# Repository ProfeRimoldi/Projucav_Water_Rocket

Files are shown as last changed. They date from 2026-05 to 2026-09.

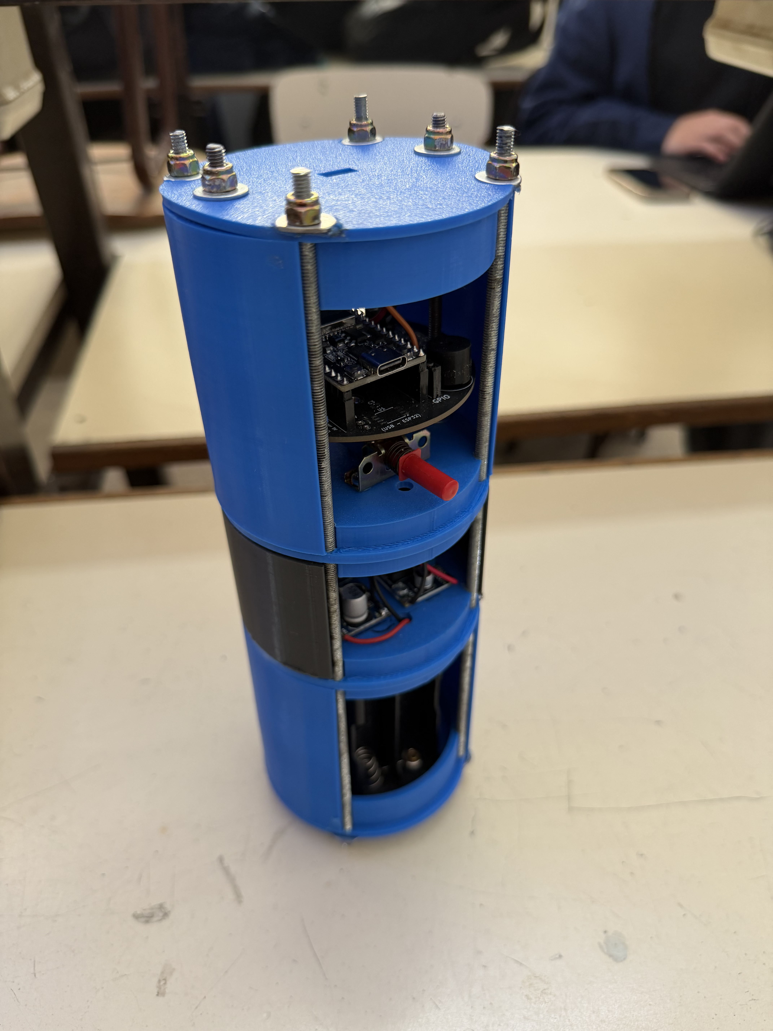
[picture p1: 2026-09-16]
hardware/Photos/IMG_1534.jpeg

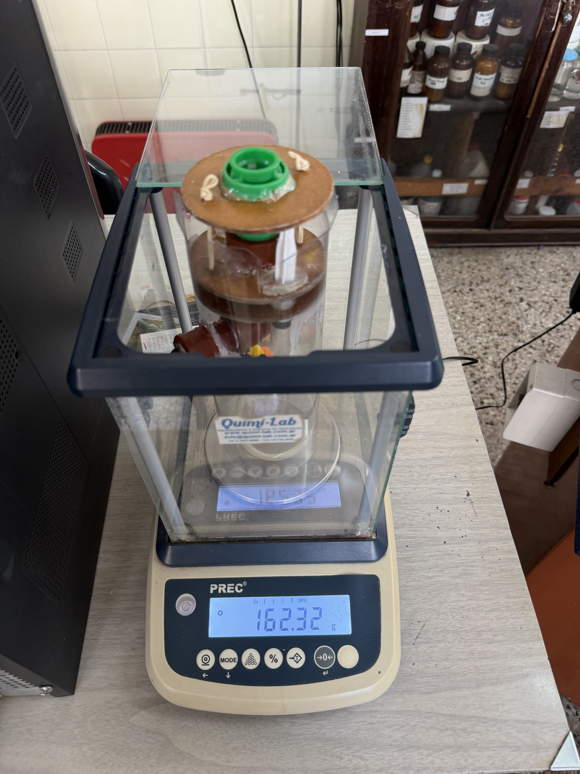
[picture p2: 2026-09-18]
hardware/Photos/IMG_1558.jpeg

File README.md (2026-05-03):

# 🚀 ProJuCAv – Water Rocket with Avionics

## 📡 Descripción del Proyecto

**ProJuCAv (Proyecto de Cohete de Agua con Aviónica)** es una iniciativa educativa basada en metodologías STEM que integra **física, electrónica, programación y diseño mecánico** en el desarrollo de un sistema aeroespacial a escala.

El proyecto propone el diseño, construcción y validación de un **cohete de agua instrumentado**, capaz de medir, registrar y transmitir datos de vuelo en tiempo real.

📘 Inspirado en programas aeroespaciales reales, el enfoque busca trasladar conceptos de ingeniería de alta complejidad a un entorno educativo práctico.

---

## 🎯 Objetivos

* Comprender los principios físicos de la **propulsión por reacción** (Tercera Ley de Newton) 
* Diseñar y construir un vehículo de lanzamiento funcional
* Desarrollar un sistema de **aviónica embarcada**
* Implementar una **estación terrena de telemetría**
* Analizar datos reales de vuelo
* Fomentar el trabajo colaborativo y multidisciplinario

📊 Según la planificación del proyecto, se estructura en etapas progresivas de diseño, integración y validación.

---

## 🧩 Arquitectura del Sistema

El sistema se divide en tres subsistemas principales:

### 🔧 Estructura (Mecánica)

* Botellas PET (fuselaje)
* Aletas aerodinámicas
* Sistema de presurización
* Plataforma de lanzamiento

### ⚡ Aviónica (Electrónica)

* Microcontrolador (ESP32)
* Sensores:

  * Altímetro barométrico (BMP280)
  * Acelerómetro (MPU6050)
* Sistema de almacenamiento local (microSD)
* Módulo de comunicación (LoRa)
* Sistema de alimentación (LiPo + regulación)

📌 La arquitectura electrónica completa se describe en 

---

### 📡 Estación Terrena

* Receptor de telemetría
* Computadora de procesamiento
* Software de visualización en tiempo real

---

## 📡 Telemetría y Adquisición de Datos

El sistema permite:

* Medición de **altura, aceleración y velocidad**
* Registro de datos en tiempo real y post-vuelo
* Transmisión inalámbrica a estación terrena

---

## 🚀 Propulsión

El cohete utiliza propulsión hidráulica basada en:

* Aire comprimido (energía potencial)
* Agua (masa de reacción)

✔ Basado en la **Tercera Ley de Newton**
✔ Expulsión de masa → generación de empuje

---

## 🪂 Sistema de Recuperación

El sistema de recuperación es crítico para la misión:

* Detección de apogeo mediante aviónica.
* Despliegue de paracaídas en apogeo.

---

## 🧪 Etapas del Proyecto

Según la planificación general:

1. **Diseño y fundamentos**
2. **Construcción del cohete**
3. **Integración de aviónica**
4. **Telemetría y pruebas**
5. **Lanzamiento final**

---

## 🛰️ Aviónica – Enfoque del Desarrollo

La aviónica evoluciona en niveles:

* 🔹 Nivel básico: sensores esenciales
* 🔹 Nivel intermedio: registro de datos (caja negra)
* 🔹 Nivel avanzado: telemetría en tiempo real
* 🔹 Nivel completo: sistema autónomo

---

## ⚙️ Tecnologías Utilizadas

* ESP32 (control principal)
* Sensores MEMS
* Comunicación inalámbrica

---

## 📁 Estructura del Repositorio

```bash
Projucav_Water_Rocket/
│
├── firmware/        # Código del sistema embebido
├── hardware/        # Diseño electrónico y PCB
├── docs/            # Documentación técnica y académica
└── README.md        # Descripción general del proyecto
```

---

## 👨‍🏫 Contexto Educativo

* Institución: Instituto Juan XXIII
* Modalidad: Aprendizaje basado en proyectos (PBL)
* Duración: ~5 meses
* Trabajo en equipos multidisciplinarios

---

## 🎓 Enfoque del Proyecto

Este proyecto busca replicar, a escala educativa, un sistema aeroespacial real, integrando:

* Ingeniería electrónica
* Física aplicada
* Programación embebida
* Diseño mecánico
* Análisis de datos

---

## 🚀 Autores / Desarrollo

**Diego Otero**; **Damián Rimoldi**
* Ingeniería en Electrónica – Docentes – Investigadores

Quien escribe:
Responsable del desarrollo de la **aviónica y sistema electrónico** del proyecto.

---

## 📌 Estado del Proyecto

🟡 En desarrollo
🔧 Etapa: Diseño e integración de sistemas

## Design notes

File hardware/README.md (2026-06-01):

Hardware Documentation.

Conexión de sensores: Usar firmware para detectar direcciones (ya cargado)
-MPU6050 (gyro) en bus I2C: DIR: 0x68
-BMP280 (Atmosferic Pressure) en bus I2C: Dir: 0x77

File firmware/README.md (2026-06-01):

# Aviónica y Telemetría en Tiempo Real - Projucav Water Rocket

Este módulo del repositorio contiene el firmware de la aviónica embarcada y de la estación terrena para el desarrollo del cohete de agua. El sistema adquiere dinámicamente datos de aceleración triaxial y altitud barométrica, implementa algoritmos de calibración y filtrado por cambio significativo en el emisor, y transmite la telemetría vía radioenlace LoRa hacia la estación terrena.

---

## 🚀 Arquitectura del Sistema

El proyecto está compuesto por dos nodos basados en microcontroladores ESP32:

1. **Nodo Emisor (Emisor_V1.ino):** Firmware embarcado en el PCB del cohete. Se encarga de la inicialización de los sensores I2C, el cálculo de offsets, el filtrado inercial/barométrico y el empaquetado de datos en formato CSV para su transmisión.
2. **Nodo Receptor (Receptor_V1.ino):** Firmware de la Estación Terrena. Escucha el espectro de RF, decodifica las ráfagas entrantes en tiempo real, procesa una máquina de estados para el análisis dinámico del vuelo y la detección automática del Apogeo.

---

## 🛠️ Especificaciones de Hardware y Conectividad

### Asignación de Pines (Pinout)

Ambos PCBs dedicados implementan transceptores LoRa basados en la tecnología Semtech (SX1276/SX1278) interconectados mediante el bus SPI nativo (VSPI) de la ESP32:

| Señal LoRa | Pin ESP32 (Emisor) | Pin ESP32 (Receptor) |
| :--- | :---: | :---: |
| **MOSI** | GPIO 23 | GPIO 23 |
| **MISO** | GPIO 19 | GPIO 19 |
| **SCK** | GPIO 18 | GPIO 18 |
| **SS (CS)** | GPIO 5 | GPIO 5 |
| **DI0 (IRQ)**| GPIO 17 | GPIO 17 |
| **RST** | GPIO 2 | *No utilizado (-1)* |

### Direccionamiento I2C (Sensores Embarcados)
* **Acelerómetro / Giroscopio (MPU6050):** `0x68`
* **Sensor de Presión / Altímetro (BMP280):** `0x76` *(Dirección física corregida)*

> ⚠️ **Nota de Orientación del PCB:** El MPU6050 se encuentra montado de forma **vertical** en el PCB del cohete. Por consiguiente, el **Eje X** ha sido mapeado por software como el eje de Empuje Vertical Primario.

---

## ⚙️ Características Principales del Firmware

### 1. Calibración Automática en Rampa
Al inicializar el Emisor, el programa ejecuta una rutina de promediado estático (20 muestras) para aislar las desviaciones térmicas y mecánicas (*offsets*) de ambos sensores:
* Establece una **Línea de Base Barométrica** dinámica para fijar la altitud inicial en `0.00 metros` relativos al suelo de lanzamiento.
* Resta la aceleración inercial en reposo en los ejes laterales y compensa el eje X respecto a la gravedad local ($9.81 m/s^2$) para obtener la lectura de **Empuje Neto**.

### 2. Filtrado por Cambio Significativo (*Deadband*)
Con el fin de mitigar el ruido de fase en la rampa, economizar batería y optimizar el uso del espectro de RF de LoRa, el emisor implementa reportes por umbral dinámico:
* **Umbral de Empuje:** $\ge 0.60 m/s^2$
* **Umbral de Altitud:** $\ge 0.50 metros$
* **Transmisión de Respaldo (*Heartbeat*):** Si las variables no superan los umbrales (cohete estático), se fuerza un envío cíclico de seguridad cada `2000 ms` para validar la continuidad del enlace.

### 3. Analizador de Estados de Vuelo y Detección de Apogeo
El firmware de la estación terrena decodifica la cadena CSV recibida y evalúa los vectores de telemetría a través de una máquina de estados:
* **`EN RAMPA`**: Estado inicial de espera.
* **`PROPULSIÓN / ASCENSO`**: Se gatilla automáticamente al detectar un $Empuje > 15.0 m/s^2$.
* **`¡APOGEO DETECTADO!`**: Se procesa mediante la derivada temporal de la altitud. Al registrar `3 lecturas consecutivas descendentes` tras haber alcanzado la altura máxima, la estación confirma el apogeo y emite una alerta crítica visual. El algoritmo está diseñado para actuar como el disparador lógico del sistema de eyección del paracaídas.
* **`DESCENSO`**: Monitoreo de velocidad terminal hasta el aterrizaje.

---

## 💾 Dependencias Requeridas

Para compilar y flashear estos programas desde el IDE de Arduino, es necesario instalar las siguientes librerías desde el Gestor de Bibliotecas:

* **LoRa** (por *Sandeep Mistry*)
* **Adafruit MPU6050** (por *Adafruit*)
* **Adafruit BMP280 Library** (por *Adafruit*)
* **Adafruit Unified Sensor** (por *Adafruit*)

---

## 📊 Formato del Paquete de Datos (Telemetría Raw)

Las ráfagas transmitidas por el módulo de radio viajan de forma compacta en una única cadena de texto plana separada por comas (CSV), reduciendo el tiempo de aire al mínimo:

```csv
[Empuje_Neto_X],[Aceleracion_Y],[Aceleracion_Z],[Altitud_Relativa]

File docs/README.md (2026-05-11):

General Projetc Documentation and To-Do List:

-Agregar conexión a servo en OBC, en pin GPIO25 (pin 9 en OBC, RXGPS) el pin de PWM de éste. Conectar 5V de una fuente aparte para el consumo.

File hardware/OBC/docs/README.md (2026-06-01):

# Documentation - OBC

Esta carpeta contiene documentación técnica complementaria del proyecto.

## Contenido esperado

- decisiones de diseño
- notas de ingeniería
- cambios importantes entre revisiones
- cálculos relevantes
- validaciones y pruebas
- observaciones de fabricación
- incidencias detectadas en laboratorio

## Objetivo

Mantener trazabilidad técnica del desarrollo del hardware y facilitar futuras revisiones o rediseños.

## Decisiones de Diseño:

- En OBC se necesita agregar el sensor de presión atmosférica BMP280, para ello, tanto el giróscopo MPU6050 como el sensor de presión atmosférica compartirán el bus I2C, y se detectan las direcciónes físicas de los sensores mediante el firmware I2C_scanner.ino presente en el apartado "firmware" de la documentación.
- Se conectaron en paralelo ambos sensores usando el mismo bus I2C.

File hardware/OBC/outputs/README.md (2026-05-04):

# Outputs - OBC

Esta carpeta contiene los archivos de fabricación y exportación del PCB de la OBC Dev Board.

## Estructura

### Rev_A

Primera revisión formal de fabricación de la placa.

Contenido esperado:

- Gerbers
- Drill files
- PDF del esquemático
- Imágenes del PCB
- BOM (Bill of Materials)

## Notas

Solo deben guardarse aquí versiones consolidadas listas para fabricación o revisión formal.

No utilizar esta carpeta para archivos temporales, backups automáticos o pruebas intermedias.

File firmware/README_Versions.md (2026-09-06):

# Aviónica de Cohete de Agua — ESP32 + LoRa

File Name: EMISOR_apogeo_V2_Test
Firmware para la placa de aviónica embarcada en un cohete de agua. Lee acelerómetro y presión barométrica, detecta el despegue y el apogeo mediante una máquina de estados, y transmite telemetría por LoRa a una estación en tierra.

## Hardware

| Componente | Modelo | Notas |
|---|---|---|
| Microcontrolador | ESP32 (devkit genérica) | |
| Radio | Módulo LoRa (SX127x) a 433 MHz | |
| IMU | MPU6050 | I2C, dirección `0x68` |
| Barómetro | BMP280 | I2C, dirección `0x76` |
| Buzzer | Piezoeléctrico **pasivo** | Requiere `tone()`, no sirve con `digitalWrite` |
| Servo | Genérico (ej. liberación de paracaídas) | Alimentar aparte del 3.3V si mueve algo con resistencia |
| LED | Integrado de la placa | Verificar el pin real en tu devkit específica |

### Conexión de pines

| Señal | GPIO |
|---|---|
| LoRa SS | 5 |
| LoRa RST | 2 |
| LoRa DIO0 | 17 |
| I2C (MPU6050 + BMP280) | 21 (SDA) / 22 (SCL), por defecto |
| Buzzer | 15 |
| Servo | 13 |
| LED | 2 (fallback si la placa no define `LED_BUILTIN`) |

> ⚠️ En algunas devkits el LED integrado está en el mismo GPIO2 que el `RST` del LoRa. Confirmá el pin real de tu placa antes de volar.

## Dependencias (Arduino Library Manager)

- `LoRa` (sandeepmistry)
- `Adafruit MPU6050`
- `Adafruit BMP280`
- `Adafruit Unified Sensor`
- `ESP32Servo` (Kevin Harrington)

## Máquina de estados

```
EN_RAMPA → ASCENSO → DESCENSO → FINALIZADO
```

- **EN_RAMPA → ASCENSO**: empuje neto sostenido por encima de `UMBRAL_DESPEGUE` durante `MUESTRAS_DESPEGUE` lecturas consecutivas.
- **ASCENSO → DESCENSO (apogeo)**: la altitud cae `HISTERESIS_APOGEO` metros por debajo del máximo alcanzado, sostenido por `MUESTRAS_APOGEO` lecturas (evita falsos positivos por ruido).
- **DESCENSO → FINALIZADO**: altitud por debajo de `UMBRAL_ATERRIZAJE` sostenida por `MUESTRAS_ATERRIZAJE` lecturas.

Las lecturas de altitud y empuje se suavizan con un filtro de media móvil exponencial (`ALPHA_ALTITUD`, `ALPHA_EMPUJE`) antes de evaluarse en la máquina de estados.

## Al detectar el apogeo

1. Se enciende el LED y suena el buzzer (no bloqueante).
2. El servo se mueve a `ANGULO_APOGEO`.
3. Se envía por LoRa un paquete inmediato `APOGEO,<altura>`.
4. Se espera hasta `ACK_TIMEOUT_MS` una respuesta `ACK_APOGEO,<rssi>,<snr>` de la estación en tierra.
5. Se imprime por Serial y se retransmite por LoRa un cartel con la altura y, si llegó a tiempo, el RSSI/SNR medidos en tierra.

> El RSSI/SNR de un paquete solo los conoce quien lo recibe. Para que estos valores no aparezcan siempre como "sin confirmación", la estación en tierra debe responder con `ACK_APOGEO,<rssi>,<snr>` al recibir un paquete `APOGEO,...` (usando `LoRa.packetRssi()` / `LoRa.packetSnr()`).

## Telemetría regular

Además del aviso de apogeo, se envía telemetría periódica por LoRa (formato CSV: empuje, acc_y, acc_z, altitud, estado) cada vez que hay un cambio significativo en empuje o altitud, o cada `TIMEOUT_FORZADO` ms como respaldo.

## Modo simulación

Para probar toda la lógica de la máquina de estados en el escritorio, sin sensores, cohete ni radio conectados:

```cpp
#define MODO_SIMULACION true
```

Esto genera un perfil de vuelo sintético (reposo → impulso → coast → apogeo → caída → aterrizaje) con ruido incluido, útil para validar umbrales antes de una prueba real. Volver a `false` para vuelo real.

## Calibración

Al arrancar (fuera de modo simulación), el firmware promedia 20 muestras de presión y aceleración con la placa quieta para fijar la presión de referencia (altitud 0) y los offsets del acelerómetro. **No mover la placa durante este proceso.**

File Name: EMISOR_apogeo_V3_Test
# Aviónica de Cohete de Agua — ESP32 + LoRa (sin LED / sin RSSI-SNR)

Firmware para la placa de aviónica embarcada en un cohete de agua. Lee acelerómetro y presión barométrica, detecta el despegue y el apogeo mediante una máquina de estados, y transmite telemetría por LoRa a una estación en tierra.

Esta es la versión simplificada: sin indicador LED y sin protocolo de confirmación de RSSI/SNR con la estación en tierra (por lo tanto, sin pausas ni esperas bloqueantes en ningún punto del `loop`).

## Hardware

| Componente | Modelo | Notas |
|---|---|---|
| Microcontrolador | ESP32 (devkit genérica) | |
| Radio | Módulo LoRa (SX127x) a 433 MHz | |
| IMU | MPU6050 | I2C, dirección `0x68` |
| Barómetro | BMP280 | I2C, dirección `0x76` |
| Buzzer | Piezoeléctrico **pasivo** | Requiere `tone()`, no sirve con `digitalWrite` |
| Servo | Genérico (ej. liberación de paracaídas) | Alimentar aparte del 3.3V si mueve algo con resistencia |

### Conexión de pines

| Señal | GPIO |
|---|---|
| LoRa SS | 5 |
| LoRa RST | 2 |
| LoRa DIO0 | 17 |
| I2C (MPU6050 + BMP280) | 21 (SDA) / 22 (SCL), por defecto |
| Buzzer | 15 |
| Servo | 13 |

## Dependencias (Arduino Library Manager)

- `LoRa` (sandeepmistry)
- `Adafruit MPU6050`
- `Adafruit BMP280`
- `Adafruit Unified Sensor`
- `ESP32Servo` (Kevin Harrington)

## Máquina de estados

```
EN_RAMPA → ASCENSO → DESCENSO → FINALIZADO
```

- **EN_RAMPA → ASCENSO**: empuje neto sostenido por encima de `UMBRAL_DESPEGUE` durante `MUESTRAS_DESPEGUE` lecturas consecutivas.
- **ASCENSO → DESCENSO (apogeo)**: la altitud cae `HISTERESIS_APOGEO` metros por debajo del máximo alcanzado, sostenido por `MUESTRAS_APOGEO` lecturas (evita falsos positivos por ruido).
- **DESCENSO → FINALIZADO**: altitud por debajo de `UMBRAL_ATERRIZAJE` sostenida por `MUESTRAS_ATERRIZAJE` lecturas.

Las lecturas de altitud y empuje se suavizan con un filtro de media móvil exponencial (`ALPHA_ALTITUD`, `ALPHA_EMPUJE`) antes de evaluarse en la máquina de estados.

## Al detectar el apogeo

1. Suena el buzzer (no bloqueante).
2. El servo se mueve a `ANGULO_APOGEO`.
3. Se imprime por Serial y se retransmite por LoRa un cartel con la altura del apogeo:

```
**********************************************
           !!! APOGEO DETECTADO !!!
**********************************************
Altura del apogeo: 153.72 m
**********************************************
```

No hay espera de confirmación de la estación en tierra: el `loop` sigue de largo sin pausas.

## Telemetría regular

Además del aviso de apogeo, se envía telemetría periódica por LoRa (formato CSV: empuje, acc_y, acc_z, altitud, estado) cada vez que hay un cambio significativo en empuje o altitud, o cada `TIMEOUT_FORZADO` ms como respaldo.

## Modo simulación

Para probar toda la lógica de la máquina de estados en el escritorio, sin sensores, cohete ni radio conectados:

```cpp
#define MODO_SIMULACION true
```

Esto genera un perfil de vuelo sintético (reposo → impulso → coast → apogeo → caída → aterrizaje) con ruido incluido, útil para validar umbrales antes de una prueba real. Volver a `false` para vuelo real.

## Calibración

Al arrancar (fuera de modo simulación), el firmware promedia 20 muestras de presión y aceleración con la placa quieta para fijar la presión de referencia (altitud 0) y los offsets del acelerómetro. **No mover la placa durante este proceso.**

File Name: EMISOR_apogeo_V3_Test
Se bajó el filtro del sensor BMP6050

File Name: EMISOR_apogeo_V6_lora_opcional
Si no detecta el modulo LoRa inicia igual.

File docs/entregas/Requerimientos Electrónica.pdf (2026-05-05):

## Resumen de requerimientos de electrónica – ProJuCAv

La parte electrónica del proyecto debe resolver, como mínimo, cinco funciones principales:

## 1. Unidad de control

Debe existir un microcontrolador central que actúe como cerebro del sistema y procese sensores, tome decisiones y controle salidas.En los materiales se propone como opción recomendada el ESP32, por su mayor capacidad de procesamiento, conectividad y posibilidad de trabajar con telemetría, microSD y control de actuadores.

### Requerimiento:

- seleccionar e integrar una placa basada en ESP32
- definir entradas, salidas y buses de comunicación
- ejecutar la lógica general del vuelo

## 2. Sensado de variables de vuelo

El sistema electrónico debe poder medir variables físicas del vuelo para reconstruir lo ocurrido y tomar decisiones automáticas.
Los documentos plantean como sensores principales:
- BMP280/BME280 para presión y cálculo de altura
- MPU6050 para aceleración y dinámica del vuelo

### Requerimiento:

- medir presión/altura
- medir aceleración
- tomar muestras con frecuencia suficiente para registrar el vuelo
- filtrar y procesar esas mediciones para detectar eventos

## 3. Detección de eventos de misión

La electrónica no solo debe medir: también debe interpretar el vuelo. De acuerdo con los materiales, los eventos principales son:
- detección de lanzamiento
- seguimiento del ascenso
- detección de apogeo
- gestión del descenso
Además, en el material de recuperación se remarca que el punto crítico es desplegar en el apogeo, no por tiempo fijo.

### Requerimiento:

- desarrollar firmware con máquina de estados
- detectar lanzamiento a partir del IMU
- detectar apogeo principalmente con barómetro
- validar eventos con lógica robusta para evitar falsos disparos

## 4. Actuación del sistema de recuperación

La electrónica debe poder accionar el mecanismo de recuperación.
Los PDFs muestran como opción didáctica y segura el uso de un servo mecánico para liberar el paracaídas o una tapa/escotilla.

### Requerimiento:

- controlar un servo
- mantenerlo inhibido hasta que el firmware autorice el disparo
- ejecutar la liberación en el apogeo
- asegurar una secuencia de despliegue confiable

## 5. Registro de datos

El proyecto contempla el concepto de “caja negra”, almacenando variables del vuelo en una microSD para análisis posterior.

### Requerimiento:

- guardar datos del vuelo en microSD
- registrar al menos:
- tiempo
- altura
- aceleración
- estado del sistema
- tensión de batería
- evento de despliegue

## 6. Telemetría / enlace con estación terrena

La arquitectura general del proyecto incluye un enlace entre el vehículo y la estación terrena para recibir datos en tiempo real. Esto aparece tanto en la planificación general como en los documentos de diseño electrónico.

### Requerimiento:

- transmitir datos hacia una estación terrena
- definir si el enlace será por:
- WiFi del ESP32
- RF 433 MHz
- otro medio equivalente (LoRa)
- permitir visualización y registro en tierra

## 7. Alimentación del sistema

La electrónica necesita una alimentación embarcada estable. En el material se propone una LiPo de 3,7 V con regulación para obtener tensiones estables, remarcando que la estabilidad eléctrica es crítica frente a vibraciones y caídas de tensión.

### Requerimiento:

- usar una batería embarcada
- regular tensión para alimentar:
- ESP32
- sensores
- servo
- contemplar desacople y robustez eléctrica
- monitorear nivel de batería

## 8. Interfaz de estado y diagnóstico

En la evolución del proyecto aparece la necesidad de contar con indicadores de estado, por ejemplo LED, datos de batería y señales de sistema listo.

### Requerimiento:

- incorporar al menos un LED de estado
- opcionalmente buzzer o interfaz serial
- indicar:
- encendido
- sistema listo
- armado
- vuelo
- error

## 9. Integración física dentro del cohete

La planificación del proyecto muestra que la aviónica debe integrarse físicamente dentro del vehículo, y que una de las metas de la fase de aviónica es justamente el montaje del sistema electrónico dentro de la estructura y los ajustes de balance de masa.

### Requerimiento:

- definir volumen y ubicación de la aviónica
- asegurar fijación mecánica
- ordenar cableado
- coordinar con la estructura y con el sistema de recuperación
- respetar restricciones de masa y espacio

## 10. Ensayos y validación

La planificación general contempla una etapa específica de verificación de enlace, ensayos en frío y validación del sistema completo antes del lanzamiento final.

### Requerimiento:

- realizar pruebas de:
- lectura de sensores
- registro en SD
- telemetría
- servo
- alimentación
- validar la lógica de disparo antes del vuelo
- participar en la secuencia de ensayo general tipo go/no-go

## Lista práctica de entregables electrónicos

- arquitectura electrónica definida
- selección de componentes
- esquema de conexiones
- firmware con máquina de estados
- lectura de BMP280/BME280
- lectura de MPU6050
- control de servo
- guardado en microSD
- telemetría básica
- alimentación estable con batería
- indicadores de estado
- protocolo de pruebas

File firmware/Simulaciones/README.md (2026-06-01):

# 📊 Módulo de Simulación de Vuelo (Inyector de Datos)

Este directorio contiene las herramientas de simulación de software diseñadas para validar y ensayar la lógica de la estación terrena (`Receptor_V1.ino`) en banco de pruebas, sin necesidad de realizar lanzamientos físicos ni exponer los sensores a desgastes mecánicos.

---

## 📐 Modelo Matemático Continúo (Parábola 0 a 0)

Para lograr una visualización óptima en el **Serial Plotter** del IDE de Arduino (el cual posee un búfer horizontal limitado a 500 muestras), el firmware del emisor simulado implementa una función cuadrática continua en el tiempo. Esto permite modelar de forma simétrica el ascenso y descenso del cohete de agua, asegurando que la trayectoria inicie exactamente en `0.00 metros` y finalice en `0.00 metros`.

La ecuación analítica implementada para la altitud $h(t)$ en función del tiempo $t$ es:

$$h(t) = a \cdot t \cdot (t_{total} - t)$$

Donde:
* $t_{total} = 6.0 \text{ segundos}$ (Tiempo total estimado de vuelo).
* $h_{max} = 35.0 \text{ metros}$ (Apogeo teórico parametrizado en el vértice $t = 3.0\text{s}$).
* $a = \frac{4 \cdot h_{max}}{t_{total}^2}$ (Constante de curvatura para ajustar el apogeo).

---

## ⏱️ Optimización del Espectro y Tasa de Muestreo

A diferencia del firmware de vuelo real (`Emisor_V1.ino`) que adquiere datos a 50 Hz, el emisor de simulación opera con un diferencial de tiempo comprimido:
* **Paso de tiempo ($\Delta t$):** $0.4 \text{ segundos}$.
* **Retardo del lazo (`delay`):** $400 \text{ milisegundos}$.

Esta tasa de refresco reducida permite que todo el perfil de vuelo de 6 segundos se resuelva en **16 puntos de datos** de telemetría. Gracias a esto, la curva parabólica completa se dibuja de forma estática en la pantalla del Serial Plotter del receptor, evitando que el gráfico se desplace hacia la izquierda (*scrolling*) y permitiendo un análisis visual completo del despegue y aterrizaje.

---

## 📑 Perfil de Telemetría Generado (Vectores de Fuerza)

El simulador discrimina los estados físicos del cohete de la siguiente manera:

1. **Fase de Propulsión ($0.0\text{s} \le t \le 0.4\text{s}$):** Simula la expulsión violenta de agua a presión. Presenta un pico de empuje positivo inicial de $45.0 \text{ m/s}²$ que decrece rápidamente.
2. **Fase Inercial y Caída Libre ($t > 0.4\text{s}$):** El empuje cesa. El acelerómetro pasa a registrar instantáneamente la aceleración de la gravedad pura ($-9.81 \text{ m/s}²$), mientras la altitud barométrica continúa su ascenso inercial hacia el vértice y su posterior descenso.
3. **Fase de Impacto ($t \ge 6.0\text{s}$):** Al tocar tierra de forma controlada, tanto la altitud como el empuje neto se fuerzan analíticamente a `0.00` para estabilizar las líneas del gráfico.

---

## 💻 Procedimiento de Ensayo en Banco

1. Flashear la placa de la Estación Terrena con el código receptor analítico.
2. Flashear la placa del Cohete con el código del **Emisor Simulado** ubicado en esta carpeta.
3. Conectar ambas placas por USB, abrir el **Serial Plotter** en el puerto del receptor (configurado a **115200 baudios**).
4. Abrir el Monitor Serie común en el puerto del emisor, escribir la letra `D` (Despegue) y presionar *Enter*.
5. **Resultado esperado:** El receptor graficará en tiempo real la parábola de altitud en sincronía con los cambios de estado de la aviónica, permitiendo verificar la sensibilidad del algoritmo de detección de apogeo.

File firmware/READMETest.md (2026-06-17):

# 🚀 Sistema de Aviónica y Telemetría - Cohete de Agua

Este repositorio contiene las iteraciones de firmware desarrolladas para la computadora de a bordo y la estación terrena del proyecto del cohete de agua. El ecosistema de software está diseñado para abarcar desde las pruebas iniciales de hardware en laboratorio hasta el análisis dinámico de telemetría inalámbrica en tiempo real durante el vuelo.

---

## 🛠️ Estructura del Firmware y Características Técnicas

El ecosistema de código se divide en cuatro módulos principales con objetivos específicos:

### 1. `Medicion_1.ino` (Fase de Diagnóstico y Banco de Pruebas)
* [cite_start]**Propósito:** Actúa como un script básico de validación y diagnóstico inicial para comprobar la conectividad física de los periféricos en el bus $I^2C$[cite: 139].
* [cite_start]**Direccionamiento de Hardware:** Inicializa de forma directa el acelerómetro/giroscopio MPU6050 en la dirección fija `0x68` y el barómetro BMP280 en la dirección `0x76`[cite: 139, 150, 151].
* **Tratamiento Físico:** Carece de rutinas de calibración activa. [cite_start]Calcula la altitud utilizando una presión de referencia fija estandarizada al nivel del mar de $1013.25 \text{ hPa}$[cite: 140]. No descuenta el vector de la gravedad terrestre de los ejes analizados.
* [cite_start]**Tasa de Adquisición:** Configura un retraso estricto de `100 ms` ($10 \text{ Hz}$) en el bucle de ejecución[cite: 174], ideal únicamente para la inspección visual inicial en el monitor serie.

### 2. `Medicion_2.ino` (Computadora de A Bordo - Monitoreo Local)
* **Propósito:** Firmware de telemetría local enfocado en la estabilidad de datos, mitigación de ruido mecánico y análisis analítico en rampa.
* **Calibración del Origen ($0\text{ m}$):** Durante el primer segundo del arranque (`setup`), toma un promedio de 20 muestras de la presión atmosférica del entorno para fijar la presión base real ($P_{\text{base}}$), garantizando que la altitud relativa inicie exactamente en $0 \text{ metros}$ sin importar las condiciones climáticas.
* **Cálculo de Empuje Neto:** Integra una rutina para calcular los offsets de los sensores en reposo. Al eje vertical (eje X) se le sustrae el vector de la aceleración de la gravedad terrestre ($g = 9.81 \text{ m/s}^2$) para aislar el error neto del chip y medir el empuje puro del motor.
* **Filtrado Analógico/Digital:** * **MPU6050:** Activa el filtro digital pasabajo (DLPF) a una banda de `21 Hz` para amortiguar las vibraciones estructurales de alta frecuencia del cohete.
  * **BMP280:** Configura un filtro IIR $\times16$ junto a un sobremuestreo de presión de $\times16$ para suavizar picos espurios provocados por corrientes dinámicas de viento durante el ascenso.

### 3. `Emisor_V1.ino` (Computadora de A Bordo - Firmware de Vuelo Principal)
* **Propósito:** Es el código definitivo integrado en el hardware del cohete. [cite_start]Fusiona las funciones analíticas de calibración con la ráfaga de transmisión inalámbrica LoRa[cite: 139].
* [cite_start]**Lógica de Filtrado por Cambio Significativo (Smart Telemetry):** Para no saturar el canal inalámbrico (debido a la baja tasa de transferencia del enlace LoRa de largo alcance), el bucle interroga internamente a los sensores a una velocidad de $50 \text{ Hz}$ (`20 ms`) [cite: 173, 174] para capturar el instante exacto del despegue, pero solo transmite vía radio si se cumplen los siguientes criterios:
  * [cite_start]$\Delta_{\text{Empuje}} \ge 0.60 \text{ m/s}^2$ (Variación brusca de aceleración en el eje vertical X)[cite: 141, 142].
  * [cite_start]$\Delta_{\text{Altitud}} \ge 0.50 \text{ m}$ (Desplazamientos verticales superiores a 50 cm)[cite: 142, 143].
  * [cite_start]**Heartbeat de Seguridad:** Transmisión forzada por timeout si transcurren `2000 ms` sin cambios significativos [cite: 144, 145][cite_start], permitiendo validar el estado de la aviónica en tierra antes del lanzamiento[cite: 145].
* [cite_start]**Configuración RF LoRa:** Opera a una frecuencia de `433 MHz` [cite: 147][cite_start], con un ancho de banda de `125 kHz` [cite: 147, 148][cite_start], Spreading Factor `SF7` para optimizar velocidad [cite: 148] [cite_start]y una potencia máxima de transmisión configurada en `17 dBm`[cite: 148, 149].

### 4. `Receptor_V1.ino` (Estación Terrena - Módulo Receptor)
* **Propósito:** Firmware exclusivo de la placa receptora de telemetría que permanece en la base de lanzamiento conectada a la computadora terrena.
* **Operación Inalámbrica:** Configura el módulo LoRa en modo escucha asíncrona a `433 MHz` utilizando interrupciones de hardware en el pin digital `DI0` de la placa.
* [cite_start]**Parseo Analítico de Datos:** Recibe la cadena compacta en formato CSV generada por el emisor[cite: 131], procesa la posición de los delimitadores por comas y extrae ordenadamente los valores de Empuje Neto (X), Aceleraciones Laterales (Y, Z) y Altitud Relativa para mostrarlos de forma legible en el terminal serie de la PC.
* **Modo Tolerancia a Fallos:** Si la trama de datos sufre degradación de señal o interferencias mecánicas en el aire, el código omite el parseo y despliega la cadena de texto cruda en bruto (`Raw`) para evitar bloqueos del software.

---

## 📊 Matriz de Comparación Operativa

| Especificación Técnica | `Medicion_1.ino` | `Medicion_2.ino` | `Emisor_V1.ino` | `Receptor_V1.ino` |
| :--- | :---: | :---: | :---: | :---: |
| **Ubicación Física** | Cohete (Banco) | Cohete (Local) | Cohete (Vuelo) | Estación Terrena |
| **Buses de Interfaz** | $I^2C$ | $I^2C$ | $I^2C$ + SPI (LoRa) | SPI (Módulo LoRa) |
| **Frecuencia del Bucle** | $10 \text{ Hz}$ (`100ms`) | $10 \text{ Hz}$ (`100ms`) | $50 \text{ Hz}$ (`20ms` interno) | Asíncrono (RX Polling) |
| **Calibración Dinámica** | No | Sí (Fija Origen $0\text{m}$) | Sí (Fija Origen $0\text{m}$) | No aplica |
| **Filtrado Activo (DLPF)** | No | Sí (Banda a `21 Hz`) | Sí (Banda a `21 Hz`) | No aplica |
| **Criterio de Disparo** | Transmisión Continua | Transmisión Continua | Umbrales dinámicos / Heartbeat | Recepción de paquete válido |
| **Formato de Salida** | Texto Serie | Texto Serie | String CSV Compacto | Formateado / Raw en consola |

---

## 📡 Protocolo y Estructura de la Trama CSV

[cite_start]La comunicación inalámbrica entre la aviónica del cohete (`Emisor_V1.ino`) y la estación terrena (`Receptor_V1.ino`) utiliza un formato de cadena comprimido delimitado por comas[cite: 131]:

```text
Formato: <Empuje_Neto_X>,<Acc_Lateral_Y>,<Acc_Lateral_Z>,<Altitud_Relativa>
Ejemplo: 12.34,-0.45,0.12,38.50

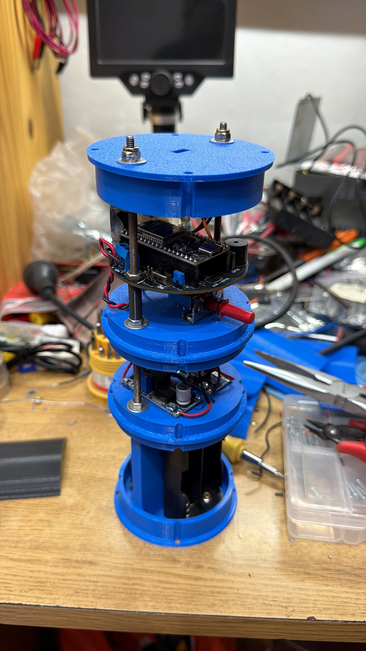
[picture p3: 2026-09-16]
hardware/Photos/6E5BA8E2-9C6F-4AE1-8FDE-30495D6D5617.jpg

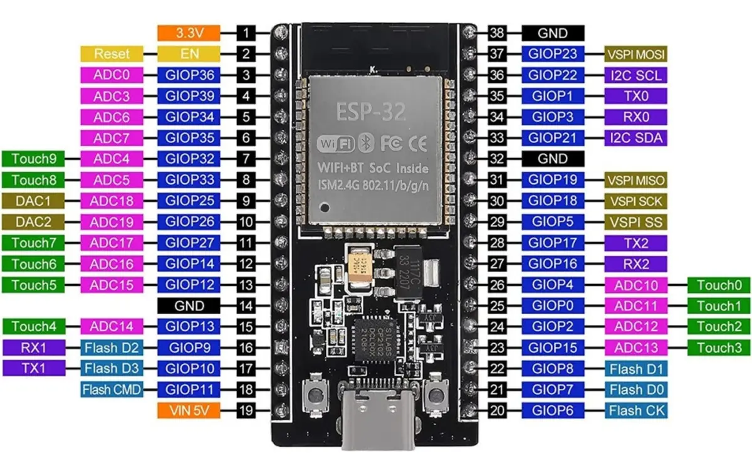
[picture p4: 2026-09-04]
docs/ESP32 pinout.png

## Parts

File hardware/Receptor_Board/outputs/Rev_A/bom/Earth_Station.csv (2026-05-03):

Reference | Value | Datasheet | Footprint | Qty | DNP
BZ1 | Buzzer |  | Buzzer_Beeper:Buzzer_TDK_PS1240P02BT_D12.2mm_H6.5mm | 1
C1,C4,C5,C6 | 100nF |  | Capacitor_SMD:C_0805_2012Metric | 4
C2 | 100uF |  | Capacitor_SMD:CP_Elec_5x3 | 1
C3 | 10uF |  | Capacitor_SMD:CP_Elec_5x3.9 | 1
D1,D2,D3,D4,D5,D6,D7,D8,D9,D11 | LED |  | LED_SMD:LED_0805_2012Metric_Pad1.15x1.40mm_HandSolder | 10
D10 | 1N4148 | https://assets.nexperia.com/documents/data-sheet/1N4148_1N4448.pdf | Diode_THT:D_DO-35_SOD27_P7.62mm_Horizontal | 1
D12 | SS34 | https://www.vishay.com/docs/88751/ss32.pdf | Diode_SMD:D_3220_8050Metric_Pad2.65x5.15mm_HandSolder | 1
esp1,esp32_1 | Conn_01x19_Pin |  | Connector_PinSocket_2.54mm:PinSocket_1x19_P2.54mm_Vertical | 2
J1,J9 | SOCKET_UP |  | Connector_PinSocket_2.54mm:PinSocket_1x02_P2.54mm_Vertical,Connector_PinSocket_2.54mm:PinSocket_1x12_P2.54mm_Vertical | 2
J2 | Screw_Terminal_01x03 |  | TerminalBlock:TerminalBlock_bornier-3_P5.08mm | 1
J3,J5 | Conn_01x08 |  | Connector_PinSocket_2.54mm:PinSocket_1x08_P2.54mm_Vertical | 2
J4,J8,J12 | PLACA |  | Connector_PinHeader_1.27mm:PinHeader_1x02_P1.27mm_Vertical,Connector_PinHeader_1.27mm:PinHeader_1x12_P1.27mm_Vertical | 3
J6 | Conn_01x04 |  | Connector_PinSocket_2.54mm:PinSocket_1x04_P2.54mm_Vertical | 1
J7 | HEADER_DOWN |  | Connector_PinHeader_2.54mm:PinHeader_1x02_P2.54mm_Vertical | 1
J15 | Screw_Terminal_01x02 |  | TerminalBlock:TerminalBlock_bornier-2_P5.08mm | 1
J16 | Conn_01x02 |  | Connector_PinSocket_2.54mm:PinSocket_1x02_P2.54mm_Vertical | 1
K1 | Relay_SPDT |  | Relay_THT:Relay_SPDT_Finder_36.11 | 1
Q1 | NPN | https://ngspice.sourceforge.io/docs/ngspice-html-manual/manual.xhtml#cha_BJTs | Package_TO_SOT_THT:TO-92L_Inline | 1
R1,R2,R3,R4,R5,R6,R7,R8,R9,R10,R11,R12,R15 | 1K |  | Resistor_SMD:R_0805_2012Metric_Pad1.20x1.40mm_HandSolder | 13
R13,R14 | R |  | Resistor_SMD:R_0805_2012Metric,Resistor_SMD:R_0805_2012Metric_Pad1.20x1.40mm_HandSolder | 2
SW1 | SW_SPDT |  | Button_Switch_THT:SW_Slide_SPDT_Straight_CK_OS102011MS2Q | 1
SW2,SW3,SW4 | SW_Push_Dual |  | Button_Switch_SMD:SW_Push_1P1T_NO_Vertical_Wuerth_434133025816 | 3
U1,U2 | LM324A | http://www.ti.com/lit/ds/symlink/lm2902-n.pdf | Package_SO:SOIC-14_3.9x8.7mm_P1.27mm | 2
U3 | L7805 | http://www.st.com/content/ccc/resource/technical/document/datasheet/41/4f/b3/b0/12/d4/47/88/CD00000444.pdf/files/CD00000444.pdf/jcr:content/translations/en.CD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 | Package_TO_SOT_SMD:TO-263-2 | 1

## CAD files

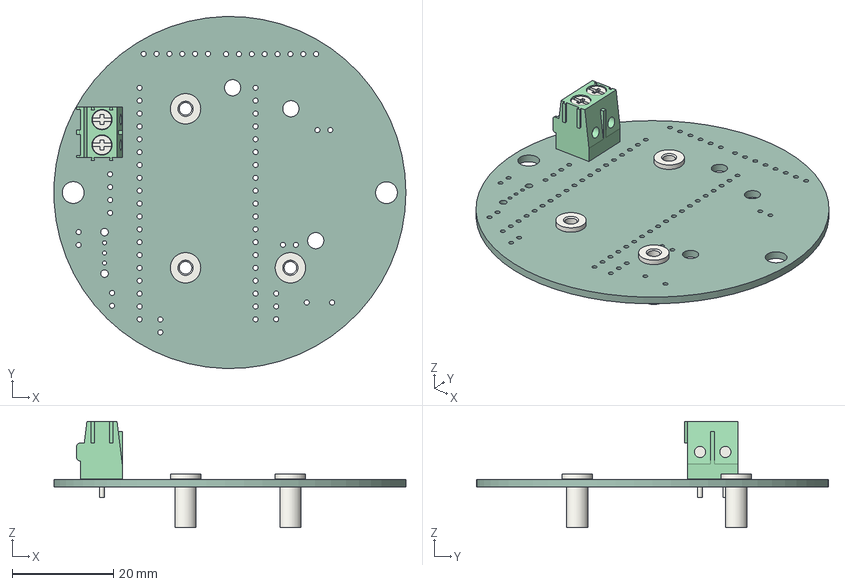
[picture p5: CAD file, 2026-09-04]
hardware/OBC/kicad/.step
69.5 x 69.5 x 21.0 mm
Mounting_Wuerth_WA-SMSR-M3_H9.6mm_ReverseMount_9775096360 x 3
TerminalBlock_Phoenix_PT-1,5-2-5.0-H_1x02_P5.00mm_Horizontal
OBC_PCB

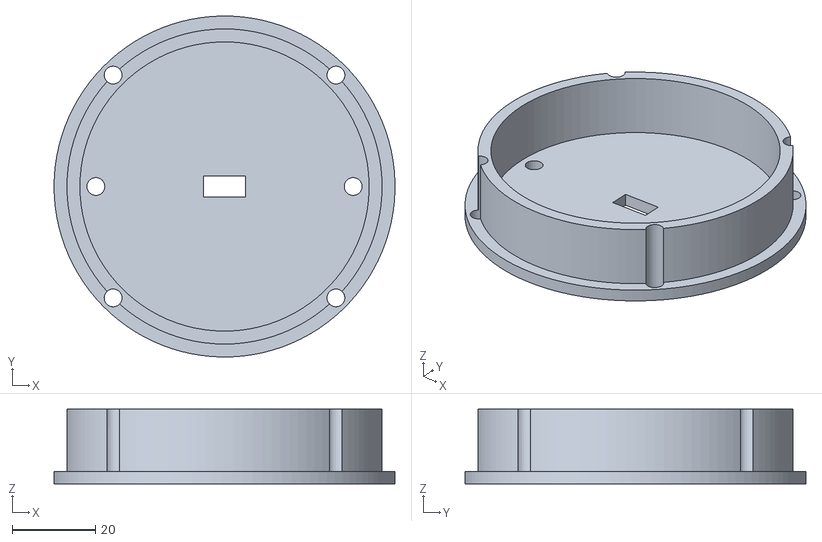
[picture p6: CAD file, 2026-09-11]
hardware/Printables/3D Models/Avionics/Ver 2/Aviónica Top Fijacion.stl
82.0 x 82.0 x 18.0

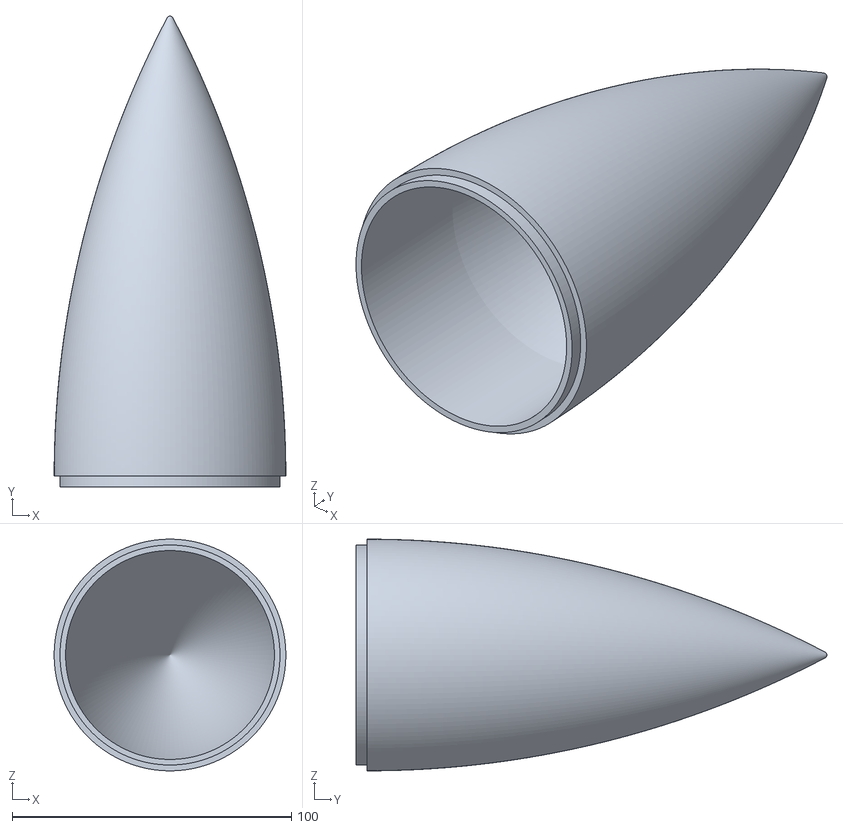
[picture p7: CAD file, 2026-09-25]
hardware/Printables/3D Models/Ogive/Ver 1/nosecone_250926_73330.stl
83.0 x 168.7 x 83.0

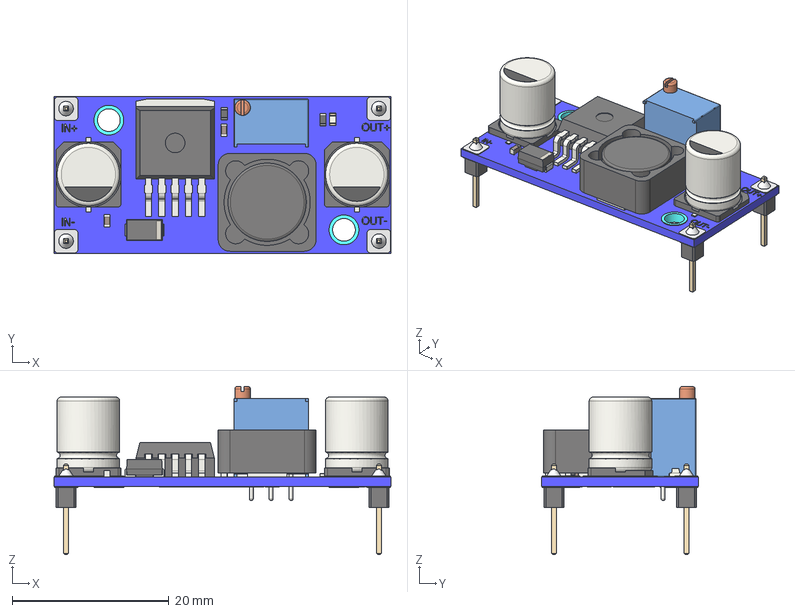
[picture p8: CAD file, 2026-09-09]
hardware/Printables/Research/LM2596.step
43.0 x 20.0 x 21.4 mm
C_Elec_8x102
C_Elec_8x103
C_Elec_8x106
C_Elec_8x107
C_0603_1608Metric
C_0603_1608Metric001
D_SMA
a648ce37-9c39-11ed-93f0-dde97e994e83_part
a648ce38-9c39-11ed-93f0-dde97e994e83_part
a648ce39-9c39-11ed-93f0-dde97e994e83_part
a648ce39-9c39-11ed-93f0-dde97e994e83_part001
a648ce39-9c39-11ed-93f0-dde97e994e83_part002
a648ce39-9c39-11ed-93f0-dde97e994e83_part003
a648ce39-9c39-11ed-93f0-dde97e994e83_part004
R_0603_1608Metric
SRR1260
Bourns_3299W
R_0603_1608Metric001
LED_0603_1608Metric
PinHeader_1x01_P254mm_Vertical
PinHeader_1x01_P254mm_Vertical001
PinHeader_1x01_P254mm_Vertical002
PinHeader_1x01_P254mm_Vertical003

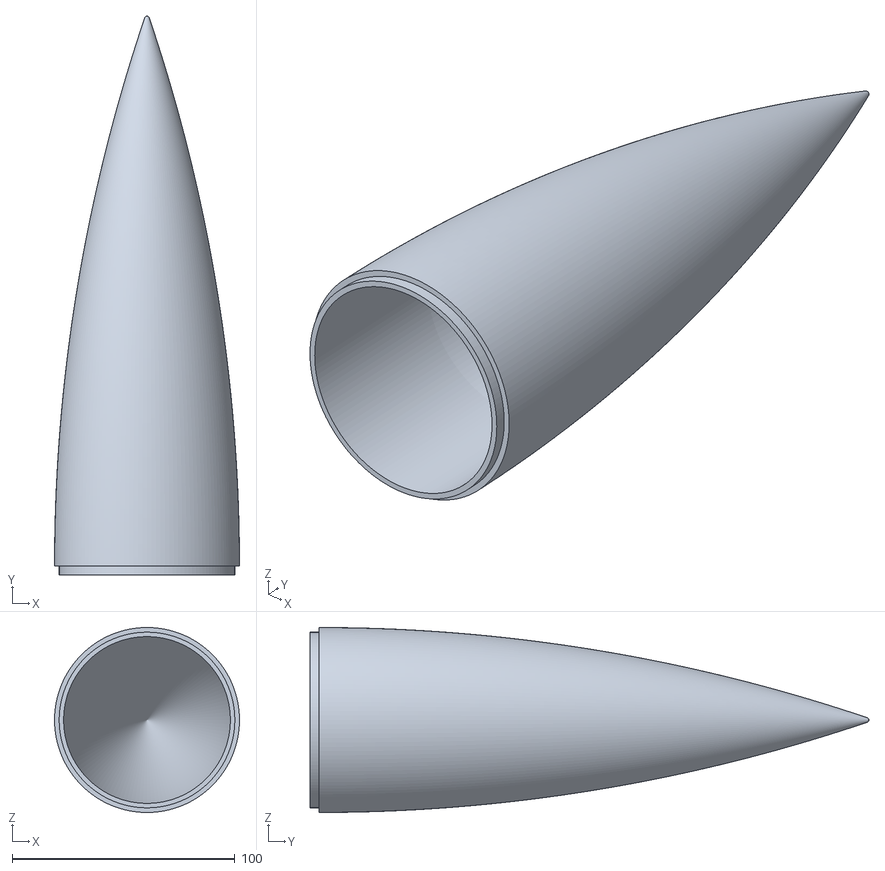
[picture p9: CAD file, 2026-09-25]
hardware/Printables/3D Models/Ogive/Ver 1/nosecone_250926_83576.stl
83.0 x 250.8 x 83.0

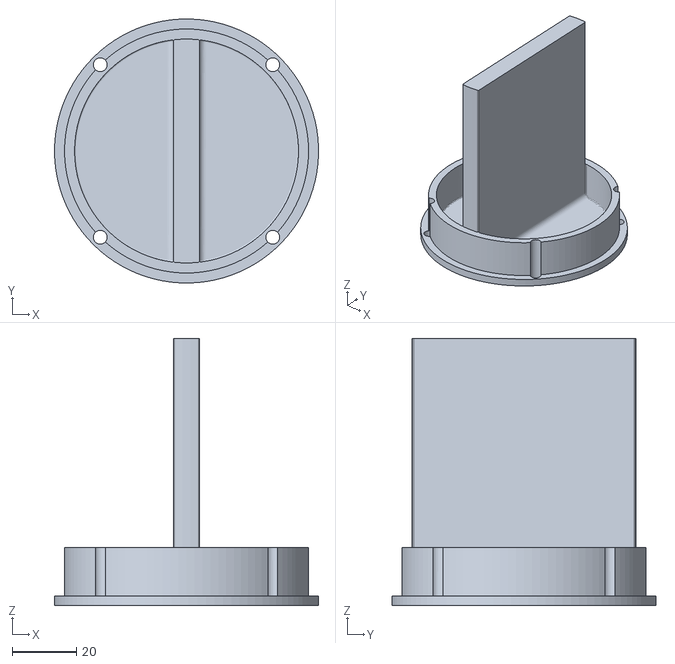
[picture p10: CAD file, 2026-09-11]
hardware/Printables/3D Models/Avionics/Ver 2/Aviónica Base Fijacion.stl
82.0 x 82.0 x 83.0

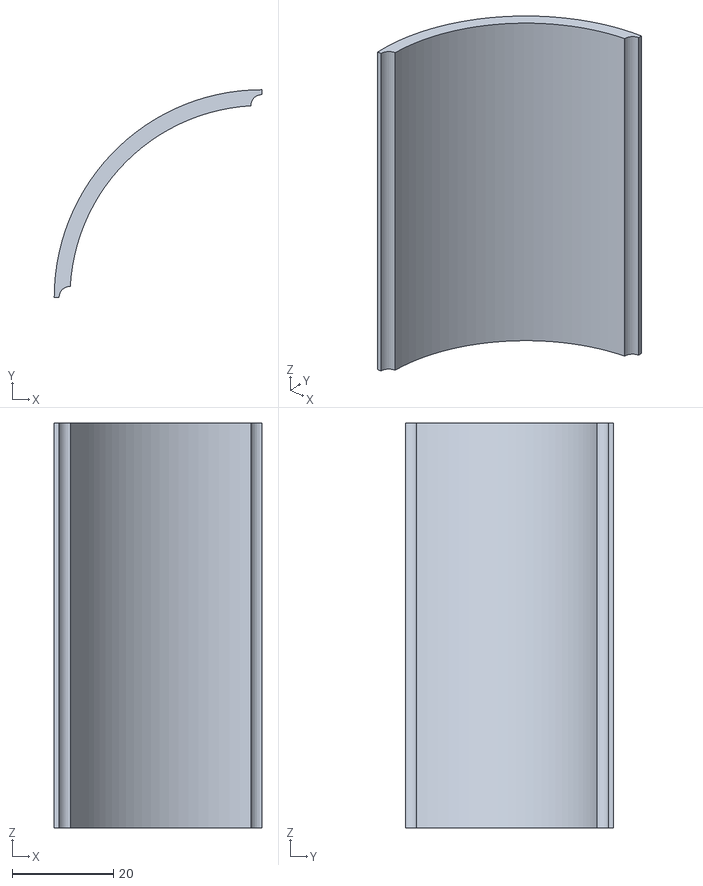
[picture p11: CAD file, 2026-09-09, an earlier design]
hardware/Printables/3D Models/Avionics/Ver 1/Aviónica Laterale Botton Middle.stl
41.0 x 41.0 x 80.0

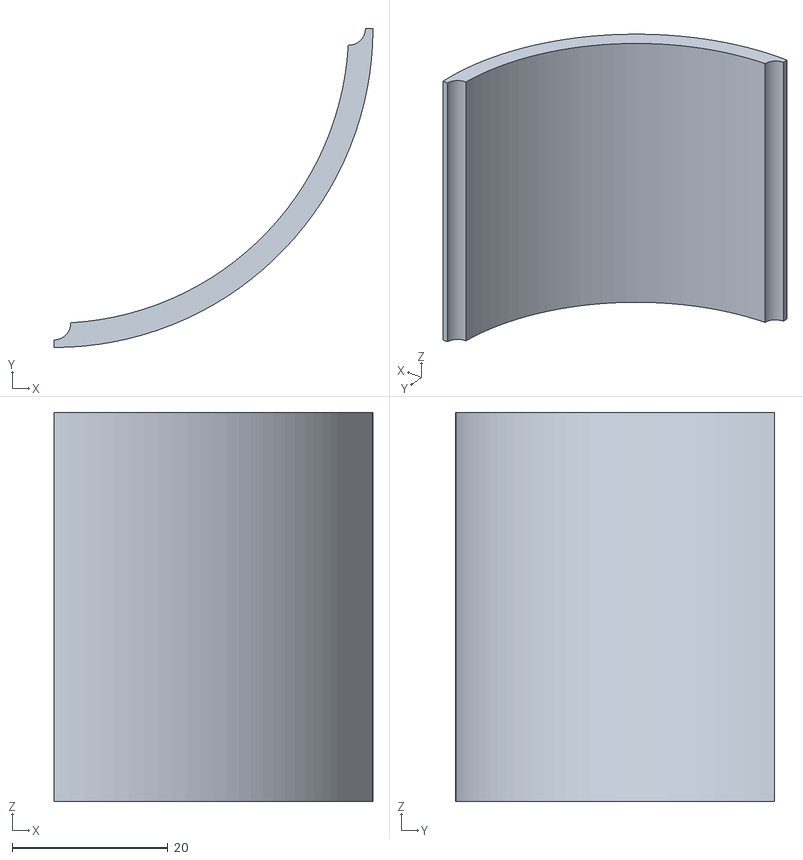
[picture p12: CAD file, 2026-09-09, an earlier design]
hardware/Printables/3D Models/Avionics/Ver 1/Aviónica Lateral middle Top.stl
41.0 x 41.0 x 50.0

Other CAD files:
hardware/Printables/3D Models/Avionics/Ver 2/Aviónica middle Fijacion.stl
hardware/Printables/3D Models/Avionics/Ver 1/Aviónica middle.stl
hardware/Printables/3D Models/Avionics/Ver 1/Aviónica.stl
hardware/Printables/3D Models/Avionics/Ver 1/Aviónica Top.stl

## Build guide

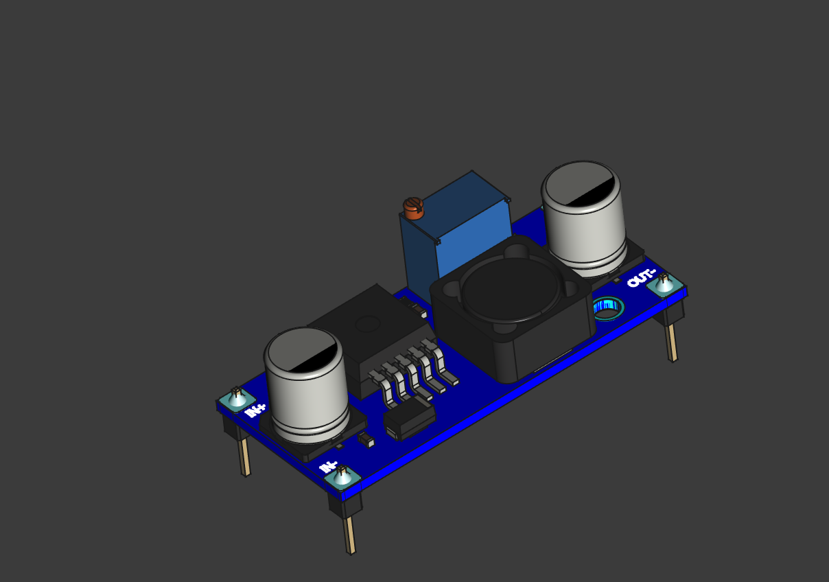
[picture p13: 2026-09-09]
hardware/Printables/Research/LM2596.png

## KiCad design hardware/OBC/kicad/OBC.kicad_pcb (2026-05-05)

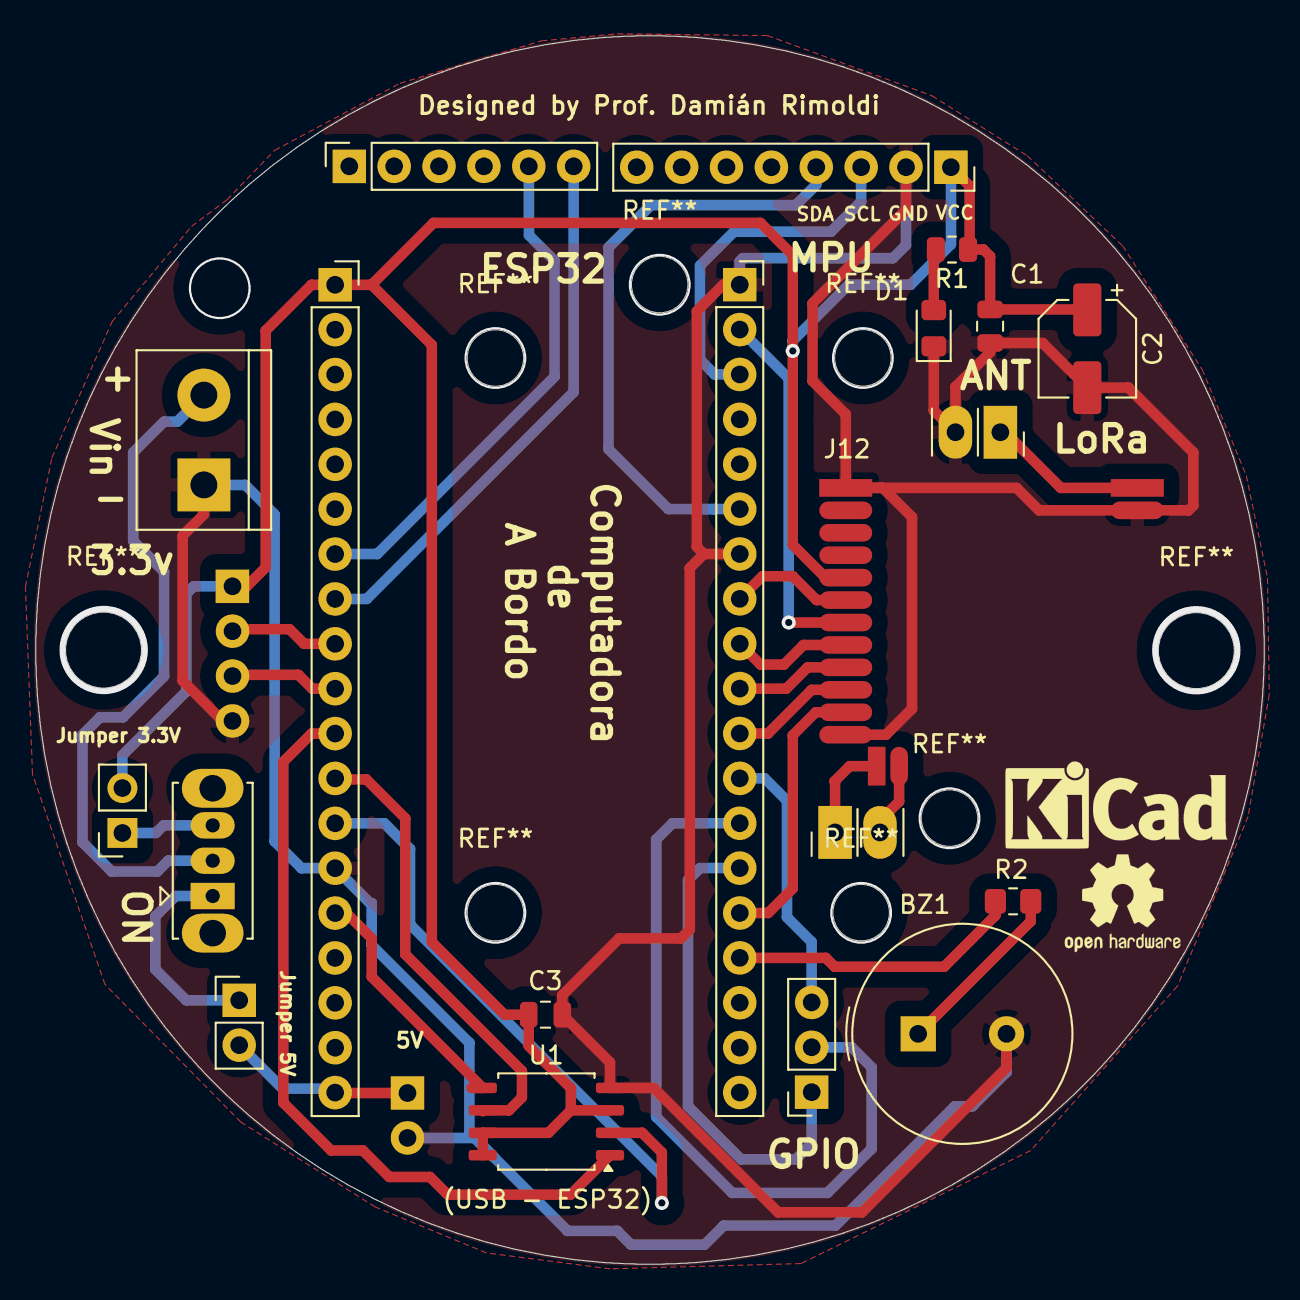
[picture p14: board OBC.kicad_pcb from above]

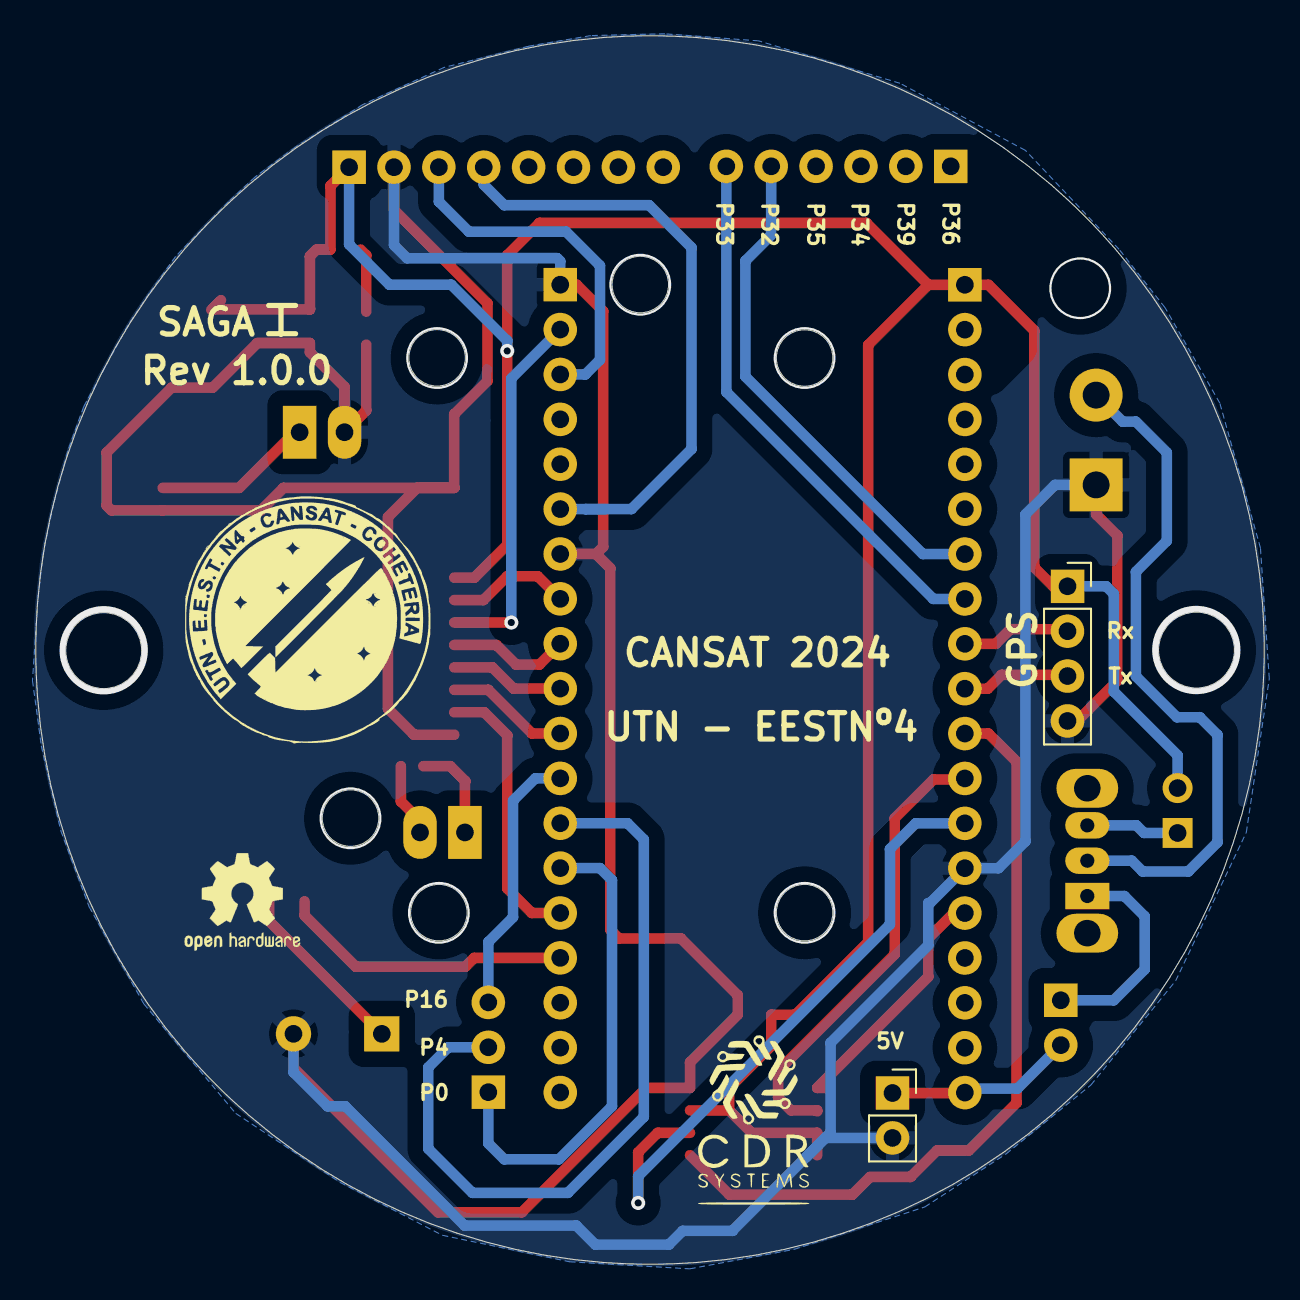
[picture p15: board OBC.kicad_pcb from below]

Board: 2 copper layers, 69.5 x 69.5 mm, 24 parts (2 on the bottom side), 35 nets.

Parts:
BZ1: Buzzer; Buzzer_TDK_PS1240P02BT_D12.2mm_H6.5mm
C1: 100nF; C_0805_2012Metric
C2: 100uF; CP_Elec_5x3.9
C3: C_Polarized_Small; C_0805_2012Metric
D1: LED; LED_0805_2012Metric_Pad1.15x1.40mm_HandSolder
J1: SOCKET_UP; PinSocket_1x02_P2.54mm_Vertical
J4, J8: PLACA; PinHeader_1x02_P1.27mm_Vertical
J7: HEADER_DOWN; PinHeader_1x02_P2.54mm_Vertical
J12: PLACA; PinHeader_1x12_P1.27mm_Vertical
J13: Conn_01x08_SocketMPU; PinSocket_1x08_P2.54mm_Vertical
J14: Conn_01x04_Socket; PinSocket_1x04_P2.54mm_Vertical
J15: Screw_Terminal_01x02; TerminalBlock_bornier-2_P5.08mm
J16, J21: Conn_01x02; PinSocket_1x02_P2.54mm_Vertical
J17: Conn_01x06_Socket; PinSocket_1x06_P2.54mm_Vertical
J18: Conn_01x02; PinHeader_1x02_P2.54mm_Vertical
J19: Conn_01x03; PinSocket_1x03_P2.54mm_Vertical
R1: 1K; R_0805_2012Metric
R2: R; R_0805_2012Metric_Pad1.20x1.40mm_HandSolder
SW1: SW_SPDT; SW_Slide_SPDT_Straight_CK_OS102011MS2Q
U1: 25CSM04xxSN; SOIC-8_5.23x5.23mm_P1.27mm
esp1, esp32_1: Conn_01x19_Pin; PinSocket_1x19_P2.54mm_Vertical

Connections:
5v: J16.1, J18.2, esp1.19
ANTENA: J1.1, J4.1
BUZZ: R2.2, esp32_1.16
DIO0: J12.10, esp32_1.11
DIO4: J7.1, J8.1
DIO5: J7.2, J8.2
GND: BZ1.2 (-), C1.2, C2.2, C3.2, D1.1 (K), J1.2, J4.2, J12.1, J12.12, J13.2, J14.4, J15.1, J16.2, U1.4 (V_{SS}), esp1.14, esp32_1.1, esp32_1.7
GPIO0: J19.1, esp32_1.14
GPIO4: J19.2, esp32_1.13
GPIO16: J19.3, esp32_1.12
GPIO32: J17.5, esp1.7
GPIO33: J17.6, esp1.8
GPIO34: J17.3, esp1.5
GPIO35: J17.4, esp1.6
GPIO36: J17.1, esp1.3
GPIO39: J17.2, esp1.4
HCLK: U1.6 (SCK), esp1.12
HMISO: U1.2 (SO), esp1.13
HMOSI: U1.5 (SI), esp1.15
HSS: U1.1 (~CS), esp1.11
INVolt: J15.2, SW1.2 (B)
MISO: J12.6, esp32_1.8
MOSI: J12.7, esp32_1.2
NSS: J12.9, esp32_1.10
unnamed: BZ1.1 (+), R2.1
unnamed: D1.2 (A), R1.2
Pup: J18.1, SW1.1 (A)
REST: J12.11, esp32_1.15
RXGPS: J14.2, esp1.9
SCLMPU: J13.3, esp32_1.3
SDAMPU: J13.4, esp32_1.6
SLCK: J12.8, esp32_1.9
TXGPS: J14.3, esp1.10
VCC: C1.1, C2.1, C3.1, J12.5, J13.1, J14.1, J21.2, R1.1, U1.3 (~WP), U1.7 (~HOLD), U1.8 (V_{CC}), esp1.1
VCC1: J21.1, SW1.3 (C)

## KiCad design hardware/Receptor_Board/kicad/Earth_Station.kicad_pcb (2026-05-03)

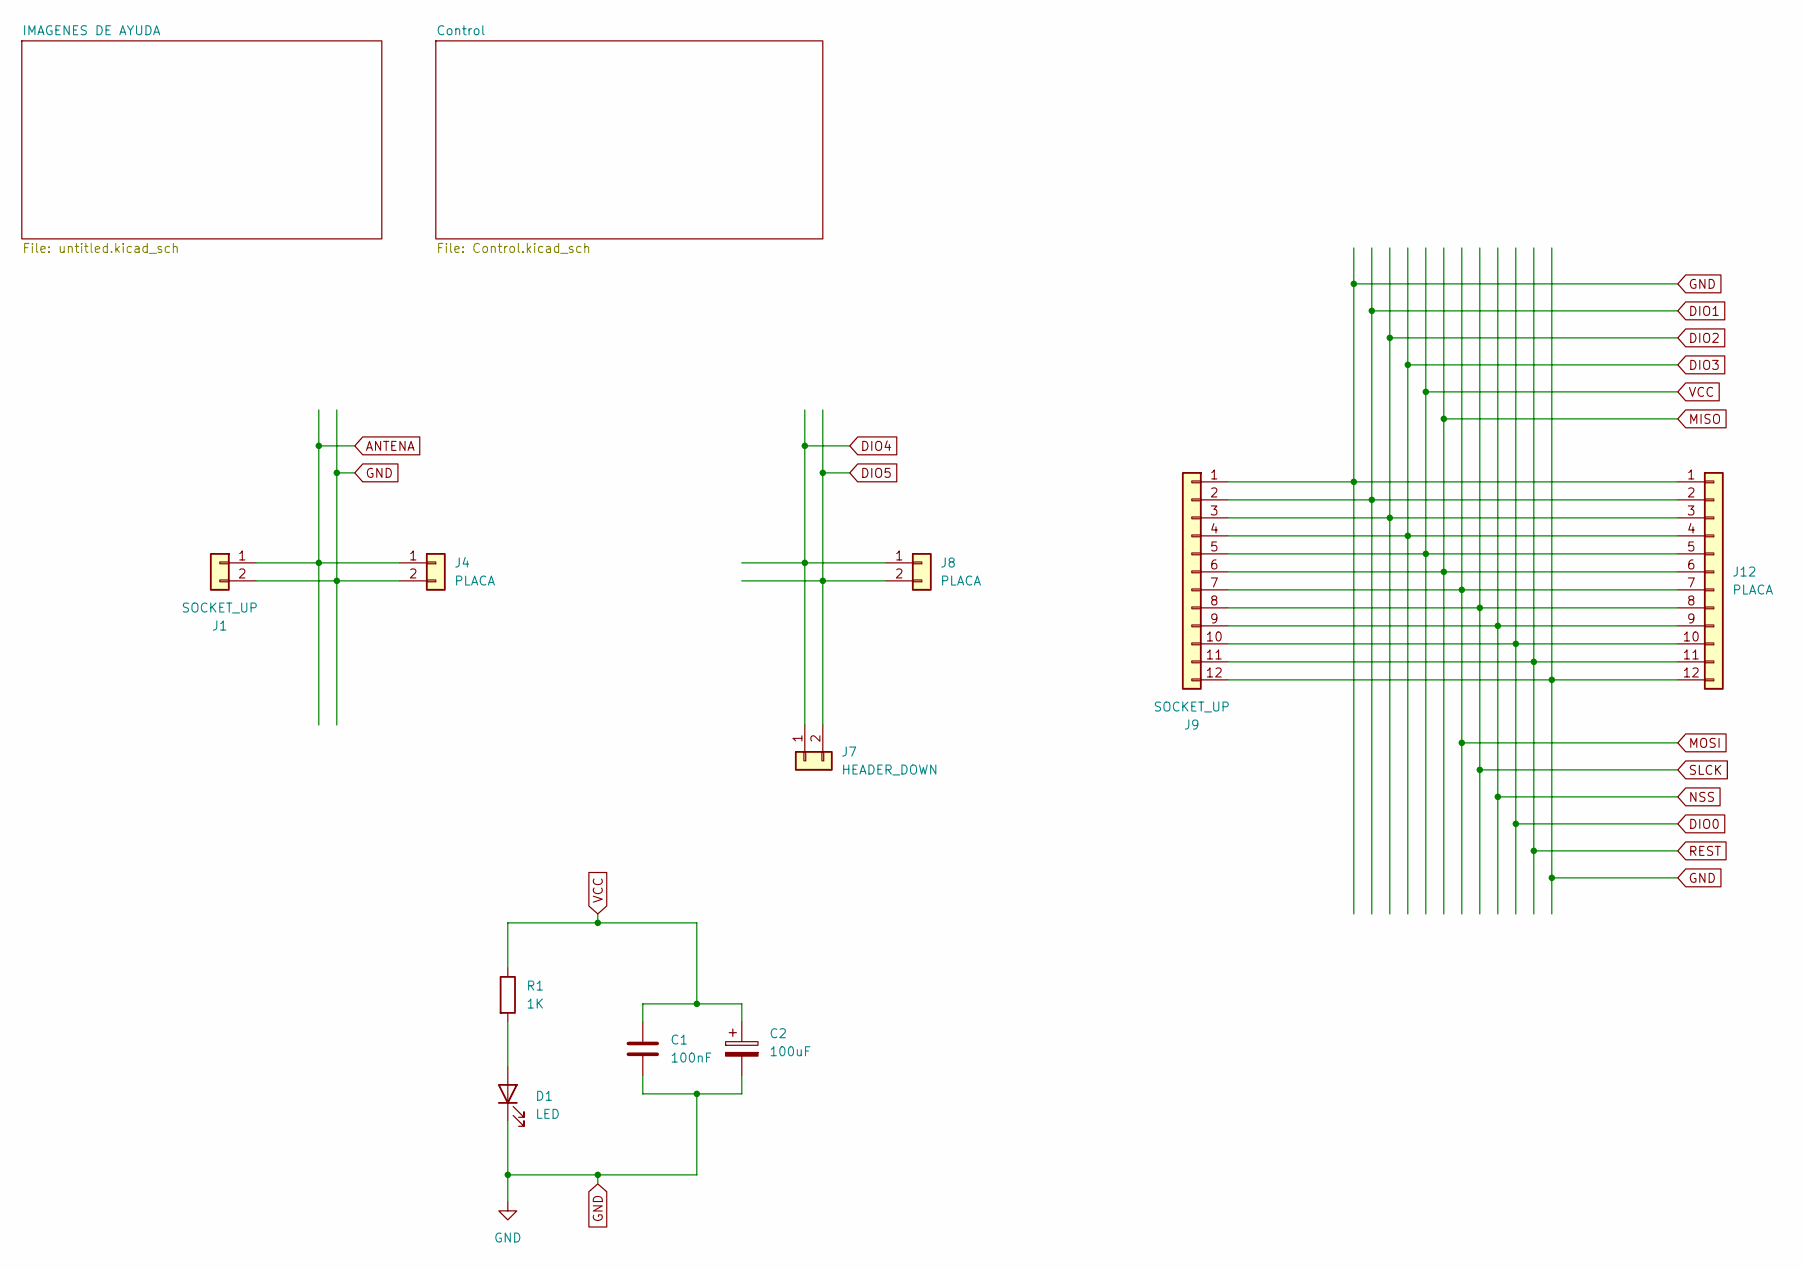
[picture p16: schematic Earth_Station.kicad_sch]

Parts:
C1: 100nF; C_0805_2012Metric
C2: 100uF; CP_Elec_5x3
D1: LED; LED_0805_2012Metric_Pad1.15x1.40mm_HandSolder
J1: SOCKET_UP; PinSocket_1x02_P2.54mm_Vertical
J4, J8: PLACA; PinHeader_1x02_P1.27mm_Vertical
J7: HEADER_DOWN; PinHeader_1x02_P2.54mm_Vertical
J9: SOCKET_UP; PinSocket_1x12_P2.54mm_Vertical
J12: PLACA; PinHeader_1x12_P1.27mm_Vertical
R1: 1K; R_0805_2012Metric_Pad1.20x1.40mm_HandSolder

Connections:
ANTENA: J1.1, J4.1
DIO0: J9.10, J12.10; also elsewhere on the board
DIO1: J9.2, J12.2
DIO2: J9.3, J12.3
DIO3: J9.4, J12.4
DIO4: J7.1, J8.1
DIO5: J7.2, J8.2
GND: C1.2, C2.2, D1.1 (K), J1.2, J4.2, J9.1, J9.12, J12.1, J12.12; also elsewhere on the board
MISO: J9.6, J12.6; also elsewhere on the board
MOSI: J9.7, J12.7; also elsewhere on the board
NSS: J9.9, J12.9; also elsewhere on the board
unnamed: D1.2 (A), R1.2
REST: J9.11, J12.11
SLCK: J9.8, J12.8; also elsewhere on the board
VCC: C1.1, C2.1, J9.5, J12.5, R1.1; also elsewhere on the board

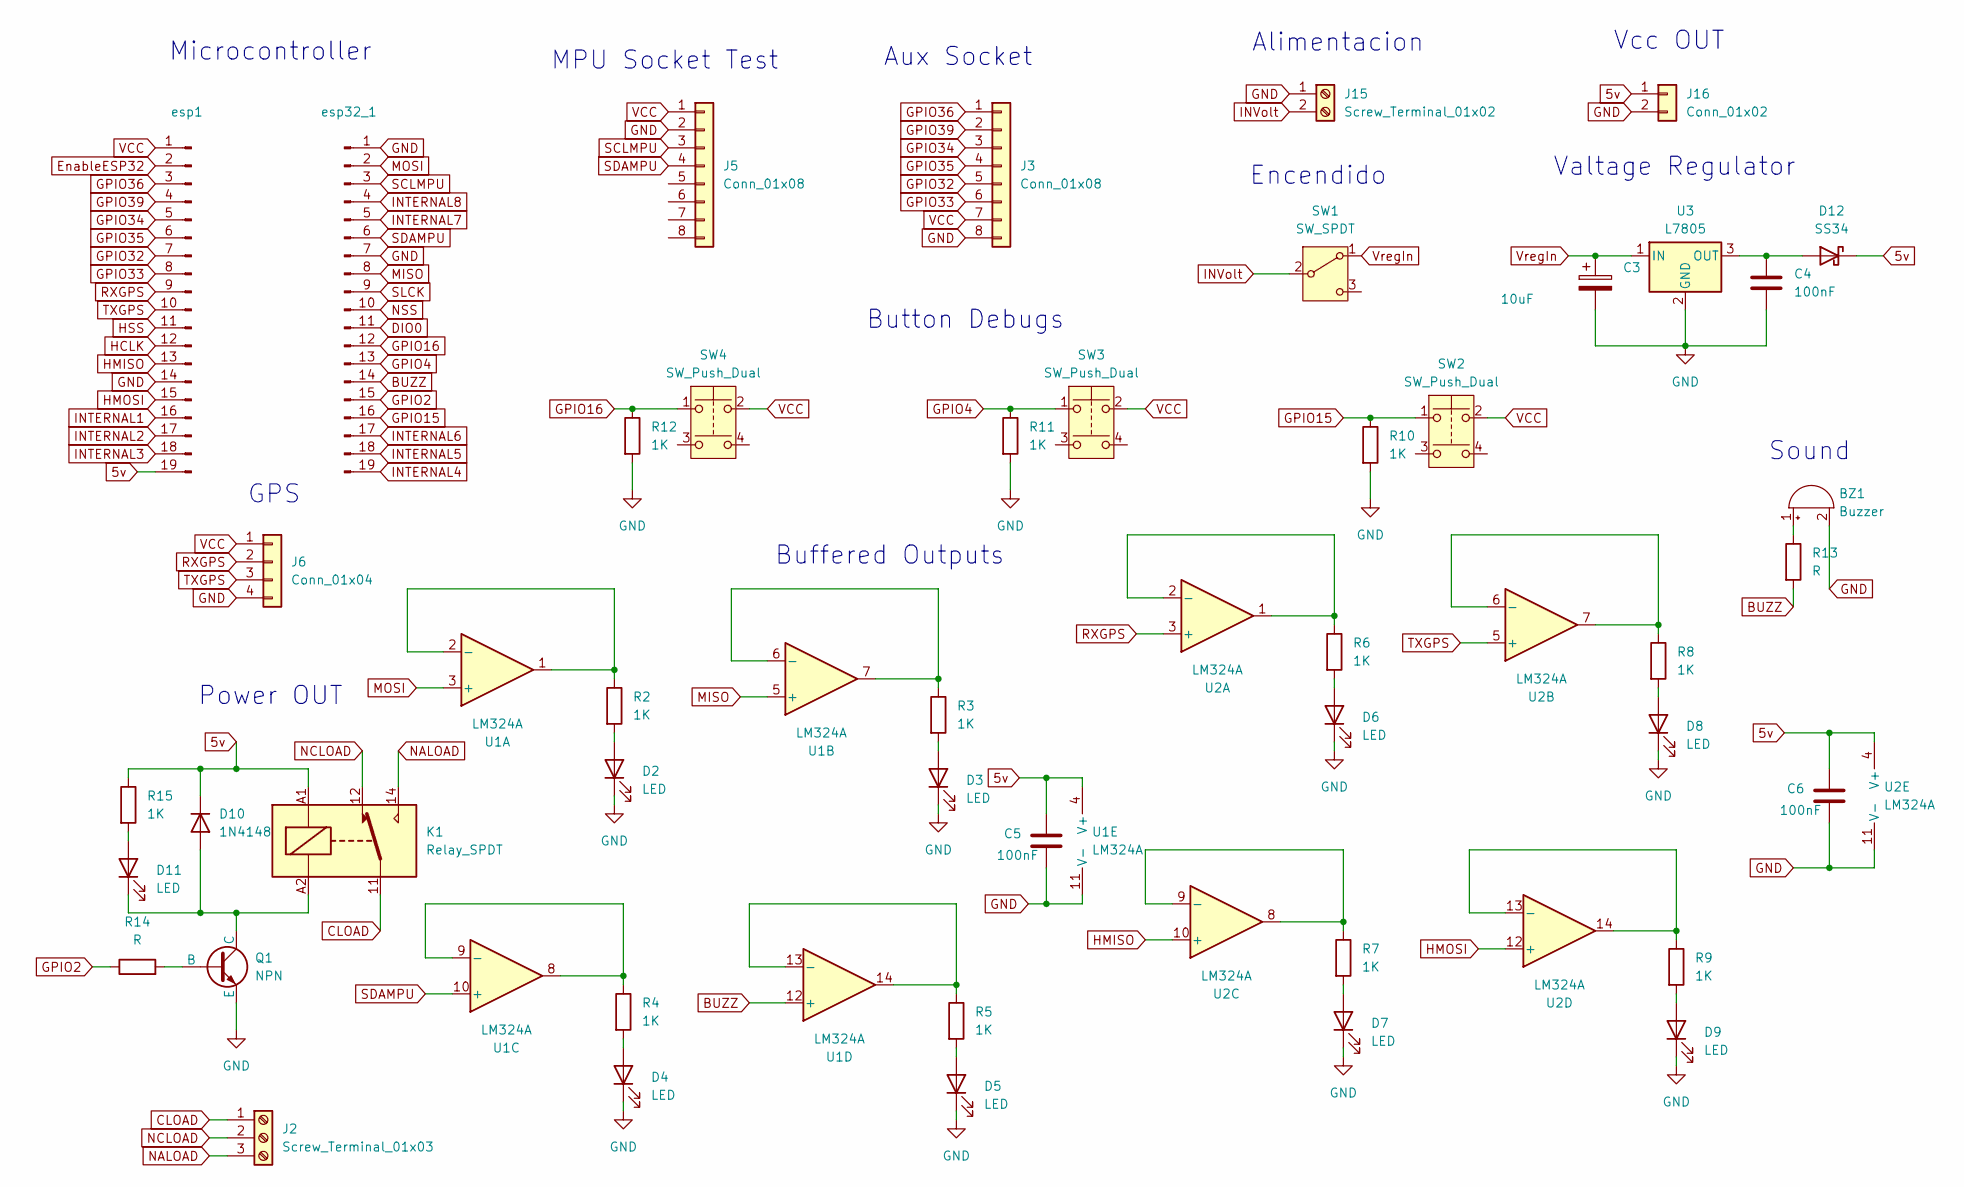
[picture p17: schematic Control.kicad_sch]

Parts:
BZ1: Buzzer; Buzzer_TDK_PS1240P02BT_D12.2mm_H6.5mm
C3: 10uF; CP_Elec_5x3.9
C4, C5, C6: 100nF; C_0805_2012Metric
D2, D3, D4, D5, D6, D7, D8, D9, D11: LED; LED_0805_2012Metric_Pad1.15x1.40mm_HandSolder
D10: 1N4148; D_DO-35_SOD27_P7.62mm_Horizontal
D12: SS34; D_3220_8050Metric_Pad2.65x5.15mm_HandSolder
J2: Screw_Terminal_01x03; TerminalBlock_bornier-3_P5.08mm
J3, J5: Conn_01x08; PinSocket_1x08_P2.54mm_Vertical
J6: Conn_01x04; PinSocket_1x04_P2.54mm_Vertical
J15: Screw_Terminal_01x02; TerminalBlock_bornier-2_P5.08mm
J16: Conn_01x02; PinSocket_1x02_P2.54mm_Vertical
K1: Relay_SPDT; Relay_SPDT_Finder_36.11
Q1: NPN; TO-92L_Inline
R2, R3, R4, R5, R6, R7, R8, R9, R10, R11, R12, R15: 1K; R_0805_2012Metric_Pad1.20x1.40mm_HandSolder
R13: R; R_0805_2012Metric_Pad1.20x1.40mm_HandSolder
R14: R; R_0805_2012Metric
SW1: SW_SPDT; SW_Slide_SPDT_Straight_CK_OS102011MS2Q
SW2, SW3, SW4: SW_Push_Dual; SW_Push_1P1T_NO_Vertical_Wuerth_434133025816
U1, U2: LM324A; SOIC-14_3.9x8.7mm_P1.27mm
U3: L7805; TO-263-2
esp1, esp32_1: Conn_01x19_Pin; PinSocket_1x19_P2.54mm_Vertical

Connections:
5v: C5.1, C6.1, D10.1 (K), D12.1 (K), J16.1, K1.A1, R15.1, U1.4 (V+), U2.4 (V+), esp1.19
BUZZ: R13.2, U1.12 (+), esp32_1.14
CLOAD: J2.1, K1.11
DIO0: esp32_1.11; also elsewhere on the board
EnableESP32: esp1.2
GND: BZ1.2 (-), C3.2, C4.2, C5.2, C6.2, D2.1 (K), D3.1 (K), D4.1 (K), D5.1 (K), D6.1 (K), D7.1 (K), D8.1 (K), D9.1 (K), J3.8, J5.2, J6.4, J15.1, J16.2, Q1.3 (E), R10.2, R11.2, R12.2, U1.11 (V-), U2.11 (V-), U3.2 (GND), esp1.14, esp32_1.1, esp32_1.7; also elsewhere on the board
GPIO2: R14.1, esp32_1.15
GPIO4: R11.1, SW3.1, esp32_1.13
GPIO15: R10.1, SW2.1, esp32_1.16
GPIO16: R12.1, SW4.1, esp32_1.12
GPIO32: J3.5, esp1.7
GPIO33: J3.6, esp1.8
GPIO34: J3.3, esp1.5
GPIO35: J3.4, esp1.6
GPIO36: J3.1, esp1.3
GPIO39: J3.2, esp1.4
HCLK: esp1.12
HMISO: U2.10 (+), esp1.13
HMOSI: U2.12 (+), esp1.15
HSS: esp1.11
INTERNAL1: esp1.16
INTERNAL2: esp1.17
INTERNAL3: esp1.18
INTERNAL4: esp32_1.19
INTERNAL5: esp32_1.18
INTERNAL6: esp32_1.17
INTERNAL7: esp32_1.5
INTERNAL8: esp32_1.4
INVolt: J15.2, SW1.2 (B)
MISO: U1.5 (+), esp32_1.8; also elsewhere on the board
MOSI: U1.3 (+), esp32_1.2; also elsewhere on the board
NALOAD: J2.3, K1.14
NCLOAD: J2.2, K1.12
NSS: esp32_1.10; also elsewhere on the board
unnamed: BZ1.1 (+), R13.1
unnamed: D2.2 (A), R2.2
unnamed: D3.2 (A), R3.2
unnamed: D4.2 (A), R4.2
unnamed: D5.2 (A), R5.2
unnamed: D6.2 (A), R6.2
unnamed: D7.2 (A), R7.2
unnamed: D8.2 (A), R8.2
unnamed: D9.2 (A), R9.2
unnamed: D10.2 (A), D11.1 (K), K1.A2, Q1.1 (C)
unnamed: D11.2 (A), R15.2
unnamed: C4.1, D12.2 (A), U3.3 (OUT)
unnamed: Q1.2 (B), R14.2
unnamed: R2.1, U1.1, U1.2 (-)
unnamed: R3.1, U1.6 (-), U1.7
unnamed: R4.1, U1.8, U1.9 (-)
unnamed: R5.1, U1.13 (-), U1.14
unnamed: R6.1, U2.1, U2.2 (-)
unnamed: R8.1, U2.6 (-), U2.7
unnamed: R7.1, U2.8, U2.9 (-)
unnamed: R9.1, U2.13 (-), U2.14
RXGPS: J6.2, U2.3 (+), esp1.9
SCLMPU: J5.3, esp32_1.3
SDAMPU: J5.4, U1.10 (+), esp32_1.6
SLCK: esp32_1.9; also elsewhere on the board
TXGPS: J6.3, U2.5 (+), esp1.10
VCC: J3.7, J5.1, J6.1, SW2.2, SW3.2, SW4.2, esp1.1; also elsewhere on the board
VregIn: C3.1, SW1.1 (A), U3.1 (IN)

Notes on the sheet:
Buffered Outputs
Microcontroller
GPS
Valtage Regulator
Vcc OUT
Encendido
Alimentacion
Aux Socket
MPU Socket Test
Button Debugs
Sound
Power OUT

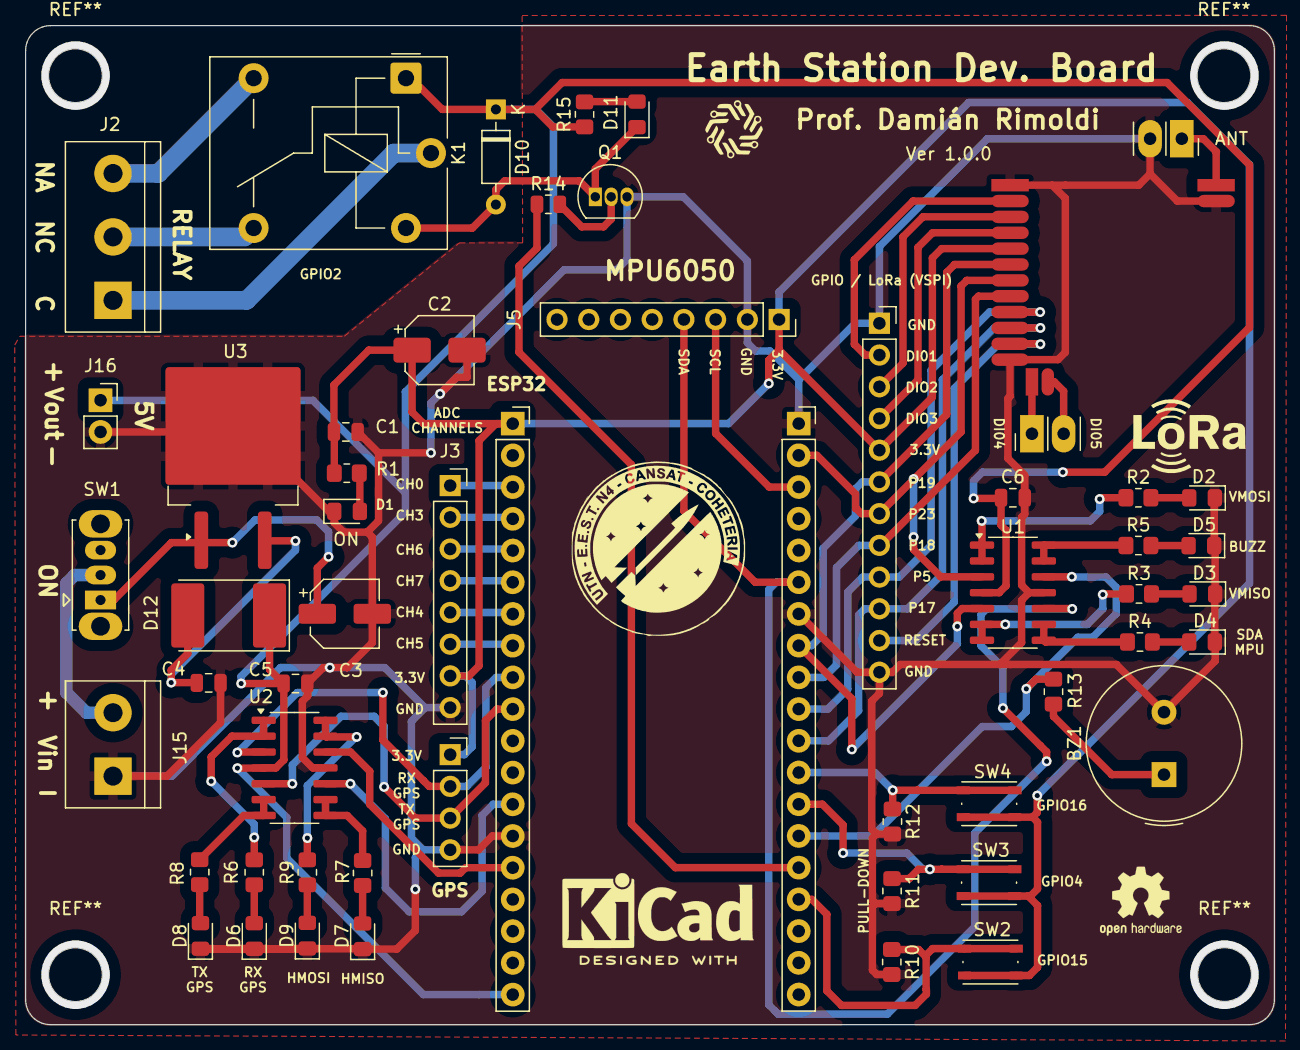
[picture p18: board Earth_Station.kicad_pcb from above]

Board: 2 copper layers, 100.0 x 80.0 mm, 57 parts (0 on the bottom side), 59 nets.

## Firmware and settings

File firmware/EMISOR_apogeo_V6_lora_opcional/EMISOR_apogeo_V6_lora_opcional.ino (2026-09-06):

#include <Wire.h>
#include <SPI.h>
#include <LoRa.h>
#include <Adafruit_MPU6050.h>
#include <Adafruit_BMP280.h>
#include <Adafruit_Sensor.h>
#include <ESP32Servo.h>  // Instalar "ESP32Servo" de Kevin Harrington desde el Gestor de Librerías

// ==================== CONFIGURACIÓN GENERAL ====================

// Poner en true para probar la máquina de estados en el escritorio,
// SIN sensores ni cohete: genera un perfil de vuelo sintético
// (rampa -> impulso -> coast -> apogeo -> caída) con ruido incluido.
// Poner en false para vuelo real con hardware conectado.
#define MODO_SIMULACION false

// Pines LoRa (según EMISOR.ino)
#define SS 5
#define RST 2
#define DI0 17

// Buzzer piezoeléctrico PASIVO (necesita tone(), no sirve con digitalWrite)
#define BUZZER_PIN 15
const unsigned int BUZZER_FRECUENCIA = 2000; // Hz
const unsigned int BUZZER_DURACION_MS = 3000; // cuánto suena al detectar el apogeo

// Servomotor (ej: liberación de paracaídas). Alimentarlo aparte del 3.3V
// de la ESP32 si va a mover algo con resistencia real.
#define SERVO_PIN 13
const int ANGULO_REPOSO = 0;
const int ANGULO_APOGEO = 90;
Servo servoRecuperacion;

Adafruit_MPU6050 mpu;
Adafruit_BMP280 bmp;

// El LoRa es telemetría, no es crítico para la misión: si no se detecta al
// arrancar, el vuelo debe continuar igual (detección de apogeo, buzzer,
// servo) simplemente sin poder avisar a tierra por radio.
bool loraDisponible = false;

// ---------- Calibración ----------
float presion_base = 1013.25;
float offset_X = 0.0, offset_Y = 0.0, offset_Z = 0.0;

// ---------- Filtrado (media móvil exponencial) ----------
// alpha bajo = más suavizado pero más lento en reaccionar; alpha alto = más
// rápido pero deja pasar más ruido. Ajustá según lo que veas en pruebas reales.
const float ALPHA_ALTITUD = 0.25;
const float ALPHA_EMPUJE  = 0.35;
float altitud_filtrada = 0.0;
float empuje_filtrado  = 0.0;
bool filtro_inicializado = false;

// ---------- Umbrales de la máquina de estados ----------
const float UMBRAL_DESPEGUE   = 3.0;   // m/s² de empuje neto sostenido para detectar despegue
const int   MUESTRAS_DESPEGUE = 3;     // muestras consecutivas por encima del umbral (debounce)

const float HISTERESIS_APOGEO = 0.5;   // metros que debe caer desde el máximo para confirmar apogeo
const int   MUESTRAS_APOGEO   = 5;     // muestras consecutivas de caída sostenida (evita falsos positivos por ruido)

const float UMBRAL_ATERRIZAJE   = 1.0; // metros, cercanía al suelo
const int   MUESTRAS_ATERRIZAJE = 25;  // ~0.5s de estabilidad a 20ms/loop, para confirmar aterrizaje

// ---------- Telemetría (throttling para no saturar el enlace LoRa) ----------
const float UMBRAL_EMPUJE_TX  = 0.60;
const float UMBRAL_ALTITUD_TX = 0.50;
const unsigned long TIMEOUT_FORZADO = 2000;
float ultimo_empuje_enviado = 0.0;
float ultima_altitud_enviada = 0.0;
unsigned long ultimo_envio_tiempo = 0;

// ---------- Diagnóstico en vivo (para depurar la detección de apogeo) ----------
// Sacá este bloque o subí el intervalo una vez que esté todo calibrado.
const unsigned long DEBUG_INTERVALO_MS = 300;
unsigned long ultimo_debug_tiempo = 0;

// ==================== MÁQUINA DE ESTADOS ====================
enum EstadoVuelo {
  EN_RAMPA,     // en la rampa, esperando despegue
  ASCENSO,      // despegue detectado, subiendo
  DESCENSO,     // apogeo detectado, cayendo
  FINALIZADO    // aterrizaje confirmado
};

EstadoVuelo estado = EN_RAMPA;

float altitud_maxima = -9999.0;
float altitud_apogeo = 0.0;
int contador_despegue = 0;
int contador_apogeo = 0;
int contador_aterrizaje = 0;

const char* nombreEstado(EstadoVuelo e) {
  switch (e) {
    case EN_RAMPA:    return "EN_RAMPA";
    case ASCENSO:     return "ASCENSO";
    case DESCENSO:    return "DESCENSO";
    case FINALIZADO:  return "FINALIZADO";
  }
  return "?";
}

// Arma el cartel de apogeo, lo imprime por Serial y lo retransmite por LoRa.
void notificarApogeo(float altura) {
  const char* linea = "**********************************************";

  String cartel = String(linea) + "\n";
  cartel += "           !!! APOGEO DETECTADO !!!\n";
  cartel += String(linea) + "\n";
  cartel += "Altura del apogeo: " + String(altura, 2) + " m\n";
  cartel += String(linea);

  Serial.println(cartel);

#if !MODO_SIMULACION
  if (loraDisponible) {
    LoRa.beginPacket();
    LoRa.print(cartel);
    LoRa.endPacket();
  }
#endif
}

// ==================== SETUP ====================
void setup() {
  Serial.begin(115200);
  while (!Serial);
  pinMode(BUZZER_PIN, OUTPUT);

  servoRecuperacion.setPeriodHertz(50);
  servoRecuperacion.attach(SERVO_PIN, 500, 2400);
  servoRecuperacion.write(ANGULO_REPOSO);

  Serial.println("\n--- Inicializando Aviónica del Cohete + LoRa ---");

#if !MODO_SIMULACION
  // 1. LoRa
  LoRa.setPins(SS, RST, DI0);
  if (!LoRa.begin(433E6)) {
    Serial.println("¡Advertencia! No se detectó el módulo LoRa. Continuando sin telemetría...");

    // Patrón de aviso sonoro DISTINTO al del apogeo, para reconocerlo de oído
    // en la rampa: 3 pitidos cortos y agudos, en vez de un tono largo único.
    for (int i = 0; i < 3; i++) {
      tone(BUZZER_PIN, 3000, 150);
      delay(300);
    }
    noTone(BUZZER_PIN);

    loraDisponible = false;
  } else {
    LoRa.setSignalBandwidth(125E3);
    LoRa.setSpreadingFactor(7);
    LoRa.setTxPower(17);
    Serial.println("-> Transmisor LoRa listo.");
    loraDisponible = true;
  }

  // 2. Sensores I2C
  if (!mpu.begin(0x68)) {
    Serial.println("¡Error MPU6050!");
    while (1);
  }
  if (!bmp.begin(0x76)) {
    Serial.println("¡Error BMP280!");
    while (1);
  }

  mpu.setAccelerometerRange(MPU6050_RANGE_16_G);
  mpu.setFilterBandwidth(MPU6050_BAND_21_HZ);

  bmp.setSampling(Adafruit_BMP280::MODE_NORMAL,
                  Adafruit_BMP280::SAMPLING_X2,
                  Adafruit_BMP280::SAMPLING_X8,   // antes X16: menos sobremuestreo, lecturas más rápidas
                  Adafruit_BMP280::FILTER_X4,     // antes X16: mucho menos retraso para un vuelo tan corto
                  Adafruit_BMP280::STANDBY_MS_1);

  // --- Calibración ---
  Serial.println("Calibrando sensores... NO MOVER LA PLACA");
  delay(1000);

  float suma_presion = 0;
  for (int i = 0; i < 20; i++) {
    suma_presion += bmp.readPressure() / 100.0F;
    delay(30);
  }
  presion_base = suma_presion / 20.0;

  sensors_event_t a, g, temp;
  float suma_X = 0, suma_Y = 0, suma_Z = 0;
  for (int i = 0; i < 20; i++) {
    mpu.getEvent(&a, &g, &temp);
    suma_X += a.acceleration.x;
    suma_Y += a.acceleration.y;
    suma_Z += a.acceleration.z;
    delay(30);
  }
  offset_X = (suma_X / 20.0) - 9.81;
  offset_Y = (suma_Y / 20.0);
  offset_Z = (suma_Z / 20.0);

  Serial.println("¡Calibración completada!");
#else
  randomSeed(analogRead(0));
  Serial.println(">>> MODO_SIMULACION activo: generando vuelo sintético, sin hardware real <<<");
#endif

  Serial.println("----------------------------------------------");
  ultimo_envio_tiempo = millis();
}

// ==================== LECTURA DE SENSORES ====================

#if MODO_SIMULACION
// Genera un perfil de vuelo falso para validar la máquina de estados en el
// escritorio, sin cohete ni sensores. Perfil: reposo -> impulso -> coast
// hasta apogeo (~24m) -> caída -> aterrizaje. Incluye ruido para simular
// las lecturas reales de un BMP280/MPU6050.
void leerSensoresSimulados(float &empuje_neto, float &altitud_relativa) {
  static unsigned long t0 = millis();
  float t = (millis() - t0) / 1000.0; // segundos desde el arranque

  float ruido_alt = random(-20, 20) / 100.0; // ±0.20 m de ruido
  float ruido_acc = random(-30, 30) / 100.0; // ±0.30 m/s² de ruido

  if (t < 1.0) {
    // en la rampa, quieto
    empuje_neto = 0.0 + ruido_acc;
    altitud_relativa = 0.0 + ruido_alt;
  } else if (t < 1.5) {
    // impulso de agua/aire
    empuje_neto = 25.0 + ruido_acc;
    altitud_relativa = (t - 1.0) * 8.0 + ruido_alt;
  } else if (t < 4.0) {
    // coast ascendente, desacelerando por gravedad
    float t_coast = t - 1.5;
    float v0 = 20.0;
    float des = 9.81;
    altitud_relativa = 4.0 + v0 * t_coast - 0.5 * des * t_coast * t_coast + ruido_alt;
    empuje_neto = -des + ruido_acc;
  } else if (t < 9.0) {
    // caída libre
    float t_caida = t - 4.0;
    float alt_en_apogeo = 24.0; // aprox, solo para esta simulación
    altitud_relativa = max(0.0f, alt_en_apogeo - 0.5f * 9.81f * t_caida * t_caida) + ruido_alt;
    empuje_neto = -9.81 + ruido_acc;
  } else {
    // aterrizado
    altitud_relativa = 0.0 + ruido_alt * 0.3;
    empuje_neto = 0.0 + ruido_acc * 0.3;
  }
}
#endif

// ==================== LOOP ====================
void loop() {
  float empuje_neto, altitud_relativa;
  float acc_y_calibrada = 0, acc_z_calibrada = 0;

#if MODO_SIMULACION
  leerSensoresSimulados(empuje_neto, altitud_relativa);
#else
  sensors_event_t a, g, temp_mpu;
  mpu.getEvent(&a, &g, &temp_mpu);

  float acc_x_calibrada = a.acceleration.x - offset_X;
  acc_y_calibrada = a.acceleration.y - offset_Y;
  acc_z_calibrada = a.acceleration.z - offset_Z;
  empuje_neto = acc_x_calibrada - 9.81; // Eje de empuje vertical (verificá orientación de montaje)

  //float presion = bmp.readPressure() / 100.0F;
  altitud_relativa = bmp.readAltitude(presion_base);
#endif

  // --- Filtrado (media móvil exponencial) para reducir ruido ---
  if (!filtro_inicializado) {
    altitud_filtrada = altitud_relativa;
    empuje_filtrado = empuje_neto;
    filtro_inicializado = true;
  } else {
    altitud_filtrada += ALPHA_ALTITUD * (altitud_relativa - altitud_filtrada);
    empuje_filtrado  += ALPHA_EMPUJE  * (empuje_neto - empuje_filtrado);
  }

  // ============ MÁQUINA DE ESTADOS (evaluada SIEMPRE, cada loop) ============
  switch (estado) {

    case EN_RAMPA: {
      if (empuje_filtrado >= UMBRAL_DESPEGUE) {
        contador_despegue++;
        if (contador_despegue >= MUESTRAS_DESPEGUE) {
          estado = ASCENSO;
          altitud_maxima = altitud_filtrada;
          contador_apogeo = 0;
          Serial.println(">>> DESPEGUE DETECTADO <<<");
        }
      } else {
        contador_despegue = 0; // se rompió la racha, reinicia el debounce
      }
      break;
    }

    case ASCENSO: {
      if (altitud_filtrada > altitud_maxima) {
        altitud_maxima = altitud_filtrada;
        contador_apogeo = 0; // seguimos subiendo, reiniciamos el contador de caída
      } else if (altitud_maxima - altitud_filtrada >= HISTERESIS_APOGEO) {
        contador_apogeo++;
        if (contador_apogeo >= MUESTRAS_APOGEO) {
          altitud_apogeo = altitud_maxima;
          estado = DESCENSO;
          contador_aterrizaje = 0;

          tone(BUZZER_PIN, BUZZER_FRECUENCIA, BUZZER_DURACION_MS); // no bloqueante
          servoRecuperacion.write(ANGULO_APOGEO);

          notificarApogeo(altitud_apogeo);
        }
      }
      break;
    }

    case DESCENSO: {
      if (altitud_filtrada <= UMBRAL_ATERRIZAJE) {
        contador_aterrizaje++;
        if (contador_aterrizaje >= MUESTRAS_ATERRIZAJE) {
          estado = FINALIZADO;
          Serial.println(">>> ATERRIZAJE CONFIRMADO <<<");
        }
      } else {
        contador_aterrizaje = 0;
      }
      break;
    }

    case FINALIZADO: {
      // Nada más que hacer: acá se podría apagar el LoRa, entrar en sleep, etc.
      break;
    }
  }

  // ============ DIAGNÓSTICO EN VIVO ============
  // Se imprime SIEMPRE, sin depender del throttling de telemetría, para ver
  // en tiempo real si el estado avanza y qué tan cerca está de disparar el
  // apogeo (útil mientras se calibra HISTERESIS_APOGEO / MUESTRAS_APOGEO).
  if (millis() - ultimo_debug_tiempo >= DEBUG_INTERVALO_MS) {
    ultimo_debug_tiempo = millis();
    Serial.print("[DEBUG] estado=");
    Serial.print(nombreEstado(estado));
    Serial.print(" | empuje_filtrado=");
    Serial.print(empuje_filtrado, 2);
    Serial.print(" | altitud_filtrada=");
    Serial.print(altitud_filtrada, 2);
    Serial.print(" | altitud_maxima=");
    Serial.print(altitud_maxima, 2);
    Serial.print(" | caida_desde_max=");
    Serial.print(altitud_maxima - altitud_filtrada, 2);
    Serial.print(" | contador_apogeo=");
    Serial.println(contador_apogeo);
  }

  // ============ TELEMETRÍA POR LoRa (throttling por cambio significativo) ============
  float delta_empuje = fabs(empuje_filtrado - ultimo_empuje_enviado);
  float delta_altitud = fabs(altitud_filtrada - ultima_altitud_enviada);
  unsigned long tiempo_actual = millis();

  bool debe_enviar = (delta_empuje >= UMBRAL_EMPUJE_TX) ||
                      (delta_altitud >= UMBRAL_ALTITUD_TX) ||
                      (tiempo_actual - ultimo_envio_tiempo >= TIMEOUT_FORZADO);

  if (debe_enviar) {
    ultimo_empuje_enviado = empuje_filtrado;
    ultima_altitud_enviada = altitud_filtrada;
    ultimo_envio_tiempo = tiempo_actual;

    String paqueteData = String(empuje_filtrado, 2) + "," +
                          String(acc_y_calibrada, 2) + "," +
                          String(acc_z_calibrada, 2) + "," +
                          String(altitud_filtrada, 2) + "," +
                          nombreEstado(estado);

    Serial.print("[");
    Serial.print(nombreEstado(estado));
    Serial.print("] Enviando: ");
    Serial.println(paqueteData);

#if !MODO_SIMULACION
    if (loraDisponible) {
      LoRa.beginPacket();
      LoRa.print(paqueteData);
      LoRa.endPacket();
    }
#endif
  }

  delay(20);
}

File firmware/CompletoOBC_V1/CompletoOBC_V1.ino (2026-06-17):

#include <Wire.h>
#include <SPI.h>
#include <LoRa.h>
#include <Adafruit_MPU6050.h>
#include <Adafruit_BMP280.h>
#include <Adafruit_Sensor.h>
#include <Servo.h> // Librería para el control del servomotor

// Pines LoRa según su PCB funcional
#define SS 5
#define RST 2
#define DI0 17

// Pin asignado para la señal de control del Servomotor (GPIO25)
#define PIN_SERVO 25 

Adafruit_MPU6050 mpu;
Adafruit_BMP280 bmp;
Servo servoParacaidas; // Objeto para controlar el servo

// Variables de calibración
float presion_base = 1013.25;
float offset_X = 0.0, offset_Y = 0.0, offset_Z = 0.0;

// Umbrales de cambio significativo para Telemetría (Ajustables)
const float UMBRAL_EMPUJE = 0.60;  // m/s²
const float UMBRAL_ALTITUD = 0.50; // metros

// --- VARIABLES PARA DETECCIÓN SEGURA DE APOGEO ---
float altitud_maxima = 0.0;
int muestras_descendientes = 0;
const int VENTANA_CONFIRMACION = 5;      // Cantidad de muestras consecutivas bajando requeridas
const float SEGURO_ALTITUD_MINIMA = 5.0; // El paracaídas NO se abre abajo de 5 metros
bool paracaidas_desplegado = false;     // Evita activaciones repetitivas

// Posiciones angulares del servomotor (Ajustar según su diseño mecánico con Diego)
const int ANGULO_BLOQUEADO = 0;   // Mecanismo cerrado reteniendo el paracaídas
const int ANGULO_DESPLEGADO = 90; // Mecanismo abierto liberando el paracaídas

// Historial de telemetría para comparar
float ultimo_empuje_enviado = 0.0;
float ultima_altitud_enviada = 0.0;

// Tiempo máximo de respaldo (Heartbeat)
unsigned long ultimo_envio_tiempo = 0;
const unsigned long TIMEOUT_FORZADO = 2000;

void setup() {
  Serial.begin(115200);
  while (!Serial);

  Serial.println("\n--- Inicializando Aviónica del Cohete + LoRa + Servo ---");

  // Inicializar Servomotor en posición de bloqueo inmediatamente por seguridad física
  servoParacaidas.attach(PIN_SERVO);
  servoParacaidas.write(ANGULO_BLOQUEADO);
  Serial.println("-> Servomotor asegurado en GPIO25 (Posición CERRADO).");

  // 1. Inicializar LoRa
  LoRa.setPins(SS, RST, DI0);
  if (!LoRa.begin(433E6)) {
    Serial.println("¡Fallo crítico en la inicialización de LoRa!");
    while (1);
  }
  
  // CONFIGURACIÓN LORA (Fuera del bloque de error para garantizar su aplicación)
  LoRa.setSignalBandwidth(125E3);    // 125 kHz estándar
  LoRa.setSpreadingFactor(7);        // SF7 por defecto (rápido)
  LoRa.setTxPower(17);               // Potencia de transmisión a 17dBm
  Serial.println("-> Transmisor LoRa configurado y listo.");

  // 2. Inicializar Sensores I2C
  if (!mpu.begin(0x68)) {
    Serial.println("¡Error MPU6050!");
    while (1);
  }
  if (!bmp.begin(0x76)) {
    Serial.println("¡Error BMP280!");
    while (1);
  }

  // Configuración de rangos y filtros de los sensores
  mpu.setAccelerometerRange(MPU6050_RANGE_16_G);
  mpu.setFilterBandwidth(MPU6050_BAND_21_HZ);
  bmp.setSampling(Adafruit_BMP280::MODE_NORMAL,
                  Adafruit_BMP280::SAMPLING_X2,
                  Adafruit_BMP280::SAMPLING_X16,
                  Adafruit_BMP280::FILTER_X16,
                  Adafruit_BMP280::STANDBY_MS_1);

  // --- PROCESO DE CALIBRACIÓN EN RAMPA ---
  Serial.println("Calibrando sensores... NO MOVER LA PLACA");
  delay(1000);

  float suma_presion = 0;
  for(int i = 0; i < 20; i++) {
    suma_presion += bmp.readPressure() / 100.0F;
    delay(30);
  }
  presion_base = suma_presion / 20.0; 

  sensors_event_t a, g, temp;
  float suma_X = 0, suma_Y = 0, suma_Z = 0;
  for(int i = 0; i < 20; i++) {
    mpu.getEvent(&a, &g, &temp);
    suma_X += a.acceleration.x;
    suma_Y += a.acceleration.y;
    suma_Z += a.acceleration.z;
    delay(30);
  }
  
  offset_X = (suma_X / 20.0) - 9.81;
  offset_Y = (suma_Y / 20.0);
  offset_Z = (suma_Z / 20.0);

  Serial.println("¡Calibración completada con éxito!");
  Serial.println("----------------------------------------------");
}

void loop() {
  sensors_event_t a, g, temp_mpu;
  mpu.getEvent(&a, &g, &temp_mpu);

  // Aplicar calibración física de aceleración
  float acc_x_calibrada = a.acceleration.x - offset_X; 
  float acc_y_calibrada = a.acceleration.y - offset_Y;
  float acc_z_calibrada = a.acceleration.z - offset_Z;
  float empuje_neto = acc_x_calibrada - 9.81; // Longitudinal vertical (Eje X)

  float presion = bmp.readPressure() / 100.0F;
  float altitud_relativa = bmp.readAltitude(presion_base);

  // =================================================================
  // 🛡️ ALGORITMO SEGURO DE DETECCIÓN DE APOGEO Y APERTURA DE PARACAÍDAS
  // =================================================================
  if (!paracaidas_desplegado) {
    
    // 1. Monitorear y registrar el punto más alto del vuelo
    if (altitud_relativa > altitud_maxima) {
      altitud_maxima = altitud_relativa;
      muestras_descendientes = 0; // Se limpia el contador porque seguimos subiendo
    } 
    // 2. Si la altitud es menor que el pico máximo registrado...
    else if (altitud_relativa < altitud_maxima && altitud_relativa > SEGURO_ALTITUD_MINIMA) {
      muestras_descendientes++; // Sumamos una muestra potencial de caída
      
      // 3. Si se cumple la ventana de persistencia, se confirma el apogeo real
      if (muestras_descendientes >= VENTANA_CONFIRMACION) {
        servoParacaidas.write(ANGULO_DESPLEGADO); // Activar el servo en GPIO25
        paracaidas_desplegado = true;             // Bloquear lógica para el resto del vuelo
        
        Serial.println("!!! APOGEO DETECTADO !!! -> PARACAÍDAS DESPLEGADO.");
        
        // Alerta inmediata por telemetría LoRa notificando el evento
        LoRa.beginPacket();
        LoRa.print("APOGEO,");
        LoRa.print(altitud_maxima, 2);
        LoRa.endPacket();
      }
    } 
    // Si la lectura fluctúa hacia arriba de manera aislada por ruido, se reinicia el contador
    else {
      muestras_descendientes = 0;
    }
  }
  // =================================================================

  // --- LÓGICA DE FILTRADO POR CAMBIO SIGNIFICATIVO (Telemetría) ---
  float delta_empuje = abs(empuje_neto - ultimo_empuje_enviado);
  float delta_altitud = abs(altitud_relativa - ultima_altitud_enviada);
  unsigned long tiempo_actual = millis();

  if (delta_empuje >= UMBRAL_EMPUJE || delta_altitud >= UMBRAL_ALTITUD || (tiempo_actual - ultimo_envio_tiempo >= TIMEOUT_FORZADO)) {
    
    ultimo_empuje_enviado = empuje_neto;
    ultima_altitud_enviada = altitud_relativa;
    ultimo_envio_tiempo = tiempo_actual;

    // Construcción de la cadena CSV estándar
    String paqueteData = String(empuje_neto, 2) + "," + 
                         String(acc_y_calibrada, 2) + "," + 
                         String(acc_z_calibrada, 2) + "," + 
                         String(altitud_relativa, 2);

    // Estado del paracaídas al final del CSV (0 = Cerrado, 1 = Desplegado)
    paqueteData += "," + String(paracaidas_desplegado ? 1 : 0);

    // 1. Consola local
    Serial.print("TX -> ");
    Serial.println(paqueteData);
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

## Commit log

2026-05-03 Incorporated Receptor Board
    [Control.kicad_sch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]
2026-05-04 Add files: On Board Computer
    [Control.kicad_sch, OBC.kicad_pcb, OBC.kicad_sch]
2026-05-04 Adapt Barometric Pressure Sensor in J17 connector socket
    [Control.kicad_sch, OBC.kicad_sch]
2026-05-04 Organize General Structure for Hardware
    [OBC.kicad_pcb, OBC.kicad_sch]
2026-05-05 First actualization for OBC PCB
    [Control.kicad_sch, OBC.kicad_pcb]
2026-05-11 Add To-Do List in README.md general file, from specification of Servo-motor Connection, and add text in Hardware OBC schematic file.
    [Control.kicad_sch]
2026-06-01 Actualizo archivos de firmware y archivos README.md de Hardware y Firmware
2026-06-01 Agrego firmware de simulacion de despegue y apogeo
2026-06-01 Agrego archivo README.md de documentacion de codigo de simulacion
2026-06-17 Fix bug on initialization of LoRa module
    [Emisor_V1.ino]
2026-09-04 Actualizacion de versiones de prueba de firmware
    [.step]
2026-09-06 Agrego EMISOR_apogeo_V4_Test_Modif_Vuelo.ino con la potencia seteada de transimison LoRa a 17 para mayor alcance, veriricar que no satura
2026-09-06 Agrego carpeta Datasheets con servo SG90
2026-09-09 Add Printables folder with first version of 3d Models
    [Aviónica Lateral middle Top.stl, Aviónica Laterale Botton Middle.stl, Aviónica Top.stl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]
2026-09-11 Add Ver 2 for printables with change of fijation
    [Aviónica Base Fijacion.stl, Aviónica Top Fijacion.stl, Aviónica middle Fijacion.stl]
2026-09-16 Add photosof the prototype
2026-09-18 Add more photos for prototype
2026-09-25 Add first version of 3D printable ogive
    [nosecone_250926_83576.stl]
2026-09-25 Reorganization of 3D printables models for avionics and ogive versions
    [Aviónica Base Fijacion.stl, Aviónica Lateral middle Top.stl, Aviónica Laterale Botton Middle.stl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]
2026-10-12 Agrego pieza para la sujecion y liberacion de la ojiva
2026-10-12 Segunda version del disparador de ojiva
2026-10-19 Modifico por inicial y final del servo para acomplarlo en la ojiva
2026-10-19 Reorganizacion de vrsiones
